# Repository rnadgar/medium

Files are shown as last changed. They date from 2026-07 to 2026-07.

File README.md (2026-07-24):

# OpenRegister — Zigbee Smart HVAC Register

A battery-powered, drop-in smart floor register for **room-by-room temperature
control** with Home Assistant. Replaces a standard 4"×10" floor register with a
3D-printed unit containing a stepper-driven damper, limit switches, a
differential-pressure fail-safe, and a Zigbee radio that runs 1–2+ years on
4× AA lithium cells.

```
Wall temp sensor ──► Home Assistant ──► Zigbee ──► register damper position
                          ▲                              │
                          └──── pressure / battery ◄─────┘
```

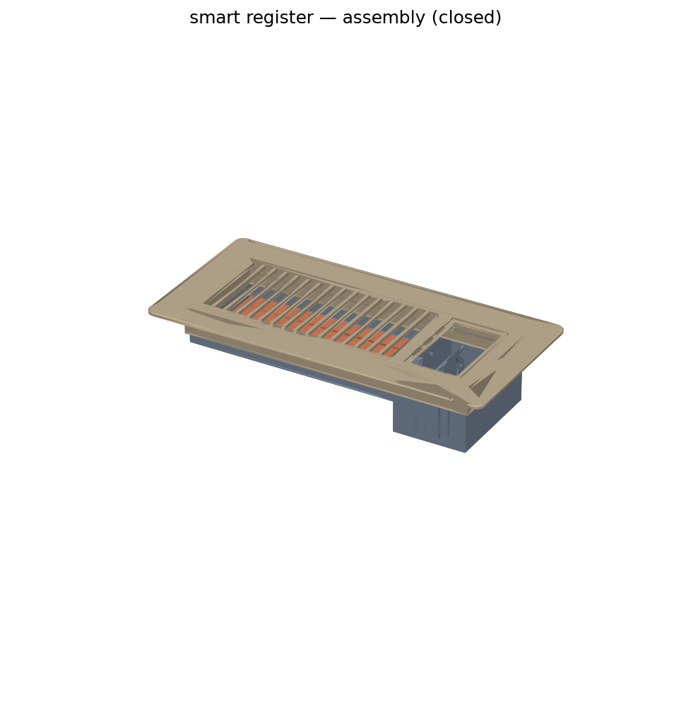
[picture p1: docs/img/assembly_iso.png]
assembly


| PCB rev A (front) | Mechanism (faceplate hidden) |
|---|---|
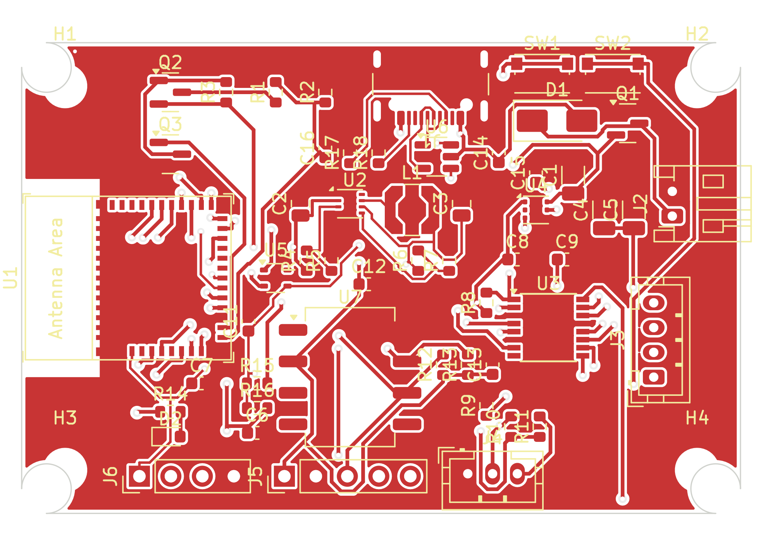
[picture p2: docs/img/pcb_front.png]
pcb
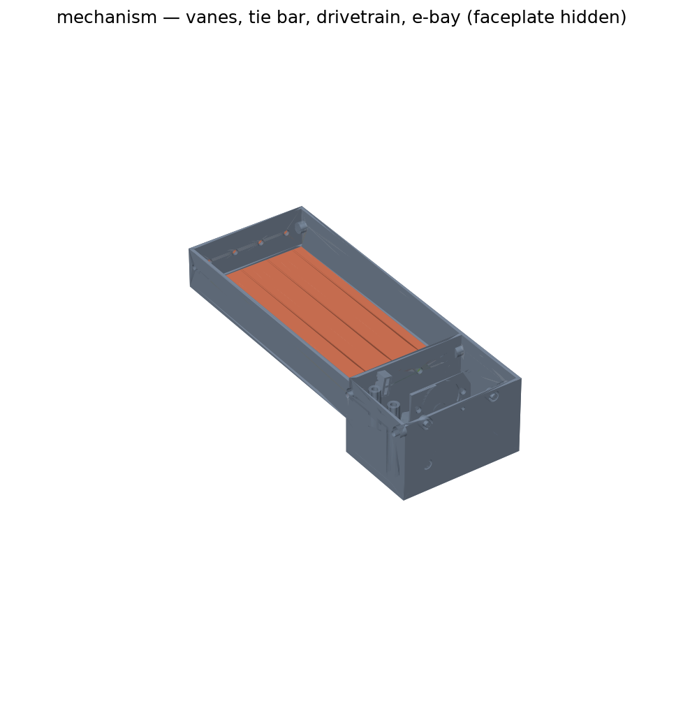
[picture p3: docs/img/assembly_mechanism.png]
mechanism
|  |  |

## Highlights

- **Zigbee sleepy end device** (ESP32-C6) — pairs with Zigbee2MQTT or ZHA and
  appears in Home Assistant as a `cover` entity with a position slider.
- **Fine-grained damper control** — 28BYJ-48 geared stepper (bipolar-modified,
  DRV8833 driver) with limit switches for homing; motor fully de-energized
  between moves.
- **Autonomous pressure fail-safe** — an onboard differential pressure sensor
  trips the damper fully open if duct static pressure exceeds a threshold,
  with **no network dependency**; an HA-side blueprint additionally keeps the
  total open area across all registers above a configurable floor.
- **Ultra-low power** — ~150 µA average draw ⇒ ≈2.4 years on 4× AA lithium
  (see [docs/power-budget.md](docs/power-budget.md)).
- **Fully parametric CAD** — the whole register is generated from one
  parameters dataclass ([build123d](https://build123d.readthedocs.io/)), so
  other register sizes are a preset away.

## Repository layout

| Path | Contents |
|---|---|
| [`docs/`](docs/) | Architecture, power budget, BOM, assembly, pairing guides |
| [`firmware/`](firmware/) | ESP-IDF + esp-zigbee-sdk firmware (C) with host-runnable unit tests |
| [`hardware/pcb/`](hardware/pcb/) | KiCad schematic + layout, fab outputs |
| [`cad/`](cad/) | build123d parametric models, STL/STEP export, pytest checks |
| [`homeassistant/`](homeassistant/) | Zigbee2MQTT converter, ZHA quirk, HA blueprints |

## Getting started

1. **Read** [docs/architecture.md](docs/architecture.md) for the system design.
2. **Buy** the parts in [docs/bom.md](docs/bom.md).
3. **Print** the register: `cd cad && pip install -e . && python export.py`
   then print the STLs in `cad/out/stl/` ([docs/assembly.md](docs/assembly.md)).
4. **Flash** the firmware: `cd firmware && idf.py set-target esp32c6 && idf.py flash`.
5. **Pair** with Zigbee2MQTT and import the blueprints
   ([docs/pairing-setup.md](docs/pairing-setup.md)).

## Status

Rev A — design complete, hardware validation in progress. Firmware bring-up
happens on an ESP32-C6-DevKitC-1 with breakout boards **before** ordering the
custom PCB; see the dev-bench section of the BOM.

## License

MIT — see [LICENSE](LICENSE).

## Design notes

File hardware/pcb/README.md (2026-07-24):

# smart-register rev A — PCB

58 × 38 mm 2-layer board for the e-bay of the smart register. ESP32-C6-MINI-1
(Zigbee), TPS62125 always-on 3.3 V buck, DRV8833 stepper driver on a
TPS22810-switched battery rail, SiP32431-switched 3.3 V sensor rail,
XGZP6897D on-board differential pressure sensor (or SDP810 on the J5 remote
header), gated battery divider, limit-switch inputs, USB-C flash/debug.

## Layout facts

- Outline/mounting contract with `cad/smart_register/params.py`:
  58 × 38 mm, M3 holes inset 3.5 mm from each corner.
- ESP32-C6 antenna at the **left board edge** with a copper/track keep-out
  under it; the CAD e-bay mounts the board vertically so this edge sits in
  the top 15 mm of the register (above the steel boot line).
- Net classes: `Default` 0.3 mm / 0.2 mm clearance; `USB` (fine-pitch USB-C
  and WSON buck nets) 0.2 mm / 0.13 mm.
- DRC: clean under KiCad 8 with the project file's net classes and severity
  settings (silk cosmetics and lib checks off — all footprints are embedded).

## Regenerating everything

The whole board is **generated from code** — do not hand-edit the outputs;
edit `tools/design.py` (netlist), `tools/gen_pcb.py` (placement), or the
generators, then:

```bash
cd hardware/pcb/tools
python3 design.py            # validate the canonical netlist
python3 gen_project.py       # .kicad_pro + lib tables
python3 gen_schematic.py     # smart-register.kicad_sch
python3 check_netlist.py     # schematic netlist == design.py (kicad-cli)
python3 gen_pcb.py           # placed board + Specctra DSN
java -jar freerouting.jar -de ../smart-register/smart-register.dsn \
     -do ../smart-register/smart-register.ses -mp 30
python3 import_ses.py        # tracks/vias + repairs + pours + stitching + DRC
python3 gen_fab.py           # gerbers/drill/BOM/CPL into ../fab/
```

Requires KiCad 7+ (pcbnew python + kicad-cli) and Java 17+ for
[Freerouting](https://github.com/freerouting/freerouting). The committed
`smart-register.ses` reproduces the committed routing exactly; only re-run
Freerouting if you change the design, and re-check DRC afterwards
(`import_ses.py` prints "DRC real issues: none" on success — its hand-repair
coordinates in `REPAIRS` are tied to the committed session and must be
revisited after any re-route).

## Ordering (JLCPCB)

1. Upload `fab/smart-register-gerbers.zip` — 2-layer, 1.6 mm FR4, any color,
   HASL or ENIG, no special options.
2. Optional assembly: `fab/bom.csv` + `fab/cpl.csv` (verify rotations in
   their preview — generated rotations follow KiCad, JLC sometimes differs
   per package).
3. **Order after validating firmware on the dev bench** (see
   `docs/bom.md` section E) — the board is validation, not the critical path.

## Bring-up checklist

1. Visual + shorts check (VBAT–GND, 3V3–GND).
2. Batteries in (or USB — SS14 feeds the pack rail at ~4.7 V for bench work):
   3.3 V rail present, ~40 µA sleep draw after flashing.
3. Flash via USB-C (`idf.py -p /dev/ttyACM0 flash` — USB-Serial-JTAG).
4. `MOTOR_PWR_EN` high → VMOT = pack voltage, sensor rail 3.3 V.
5. Motor moves, limit switches read, pressure sample returns plausible Pa.
6. Join Zigbee, then the `docs/pairing-setup.md` flow.

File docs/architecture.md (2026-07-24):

# System Architecture

Battery-powered Zigbee smart register: a drop-in 4"×10" floor register with a
stepper-actuated multi-vane damper, limit switches, differential-pressure
fail-safe, and a ~2-year battery life on 4× AA lithium (LiFeS2) cells.

## Block diagram

```mermaid
flowchart LR
    subgraph pack["4x AA LiFeS2 pack (6.0-7.2 V)"]
        BATT[VBAT]
    end
    BATT --> RPP["Reverse-polarity P-FET"]
    RPP --> BUCK["TPS62125 buck\n3.3 V always-on, Iq ~13 uA"]
    RPP --> LSW["TPS22810 load switch\nMOTOR_PWR_EN"]
    BUCK --> C6["ESP32-C6-MINI-1\nZigbee sleepy end device"]
    BUCK --> SSW["SiP32431 load switch\n3V3_SENS, MOTOR_PWR_EN"]
    LSW --> DRV["DRV8833\nstepper driver"]
    SSW --> SDP["Pressure sensor\nXGZP6897D onboard / SDP810 header (I2C)"]
    DRV --> MOT["28BYJ-48 stepper\n(bipolar mod) + gear train"]
    MOT --> VANES["Linked damper vanes"]
    SW1["Limit switch OPEN"] --> C6
    SW2["Limit switch CLOSED"] --> C6
    SDP -->|I2C| C6
    C6 -->|AIN1..BIN2| DRV
    RPP --> DIV["Gated divider\nVBAT_SENSE"]
    DIV --> C6
```

Two power domains:

- **Always-on 3.3 V** (TPS62125): the ESP32-C6 and nothing else. The buck's
  ~13 µA quiescent current plus the C6 in light sleep sets the sleep floor.
- **Switched VBAT "VMOT"** (TPS22810, `MOTOR_PWR_EN`): DRV8833 stepper
  driver. (TPS22919/SiP32431-class switches are 5.5 V-max parts — below the
  7.2 V fresh pack — hence the 18 V-rated TPS22810 here.)
- **Switched 3.3 V "3V3_SENS"** (SiP32431 from the 3.3 V rail, same
  `MOTOR_PWR_EN` signal): pressure sensor + I2C pull-ups. Energized only
  during moves and pressure samples; parked leakage ≤ 1 µA total.

The pressure sensor has two mutually exclusive fit options: XGZP6897D
directly on board (cost-down default) or an SDP810 connected to the 5-pin
remote-sensor header (premium accuracy; also mechanically flexible for tube
routing).

## Pin map

Single source of truth — `firmware/main/board.h` mirrors this table and is
selected per-board with `idf.py menuconfig` (Kconfig choice `BOARD_*`).

| Signal | Rev A GPIO | DevKitC-1 GPIO | Dir | Notes |
|---|---|---|---|---|
| `VBAT_SENSE` | 0 | 0 | AI | ADC1_CH0, 1 M / 330 k divider |
| `VBAT_SENSE_EN` | 1 | 1 | O | High = divider connected (NFET → P-FET) |
| `MOTOR_AIN1` | 2 | 2 | O | DRV8833 AIN1 |
| `MOTOR_AIN2` | 3 | 3 | O | DRV8833 AIN2 |
| `MOTOR_BIN1` | 4 | 4 | O | DRV8833 BIN1 |
| `MOTOR_BIN2` | 5 | 5 | O | DRV8833 BIN2 |
| `I2C_SDA` | 6 | 6 | IO | Pressure sensor bus (on switched rail) |
| `I2C_SCL` | 7 | 7 | O | |
| `BOOT_BTN` | 9 | 9 | I | Boot strap; long-press = factory reset / pair |
| `USB_D-` / `USB_D+` | 12 / 13 | (USB conn) | IO | USB-Serial-JTAG flash/debug |
| `UART_TX` / `UART_RX` | 16 / 17 | 16 / 17 | O/I | Debug header |
| `LIMIT_OPEN` | 18 | 18 | I | Closes to GND at full-open travel |
| `LIMIT_CLOSED` | 19 | 19 | I | Closes to GND at full-closed travel |
| `STATUS_LED` | 20 | 8 (onboard) | O | Identify blink, fault codes |
| `MOTOR_PWR_EN` | 21 | 21 | O | Load-switch EN, high = motor + sensor rails powered |
| `LIMIT_SENSE_EN` | 22 | 22 | O | Sources the limit-switch pull-ups during moves only |
| `SENS_IRQ` (spare) | 23 | 23 | I | Reserved on the remote-sensor header |

> GPIO10/11 are **not bonded out** on the ESP32-C6-MINI-1 module — do not
> assign them. Free for future use: GPIO14, GPIO15.

Limit switches are wired switch→GND on the input side with their pull-up side
fed from `LIMIT_SENSE_EN`, so there is **zero standby current** through the
switch network; inputs are only meaningful while the CPU is awake and moving
the motor (no GPIO wake needed).

## Zigbee device model

Sleepy End Device (`rx_on_when_idle = false`), one application endpoint.

Manufacturer **"OpenRegister"**, model **"SR-4x10"**, endpoint **1**, profile
Home Automation (0x0104), device id Window Covering Device (0x0202).

| Cluster | ID | Role | Use |
|---|---|---|---|
| Basic | 0x0000 | server | mfr/model/date/sw build strings |
| Power Configuration | 0x0001 | server | `BatteryVoltage` 0x0020, `BatteryPercentageRemaining` 0x0021 (reportable, 0.5 % units) |
| Identify | 0x0003 | server | status LED blink |
| Poll Control | 0x0020 | server | coordinator-tunable long/short poll |
| Window Covering | 0x0102 | server | primary control — see below |
| Pressure Measurement | 0x0403 | server | `ScaledValue` 0x0010 / `Scale` 0x0014 (Pa resolution); `MeasuredValue` also kept coherent |
| OTA Upgrade | 0x0019 | client | phase 2 (partition slots reserved now) |
| **Fail-safe (mfr-specific)** | **0xFC00** | server | see table below |

### Window Covering semantics — the one inversion, stated once

ZCL lift percentage: **0 % = fully open (damper open, max airflow), 100 % =
fully closed**. Firmware stores damper position as `open_pct` and maps at the
cluster boundary only:

```
lift_pct = 100 - open_pct
```

`CurrentPositionLiftPercentage` (0x0008) is reportable. Supported commands:
`UpOrOpen` (0x00), `DownOrClose` (0x01), `Stop` (0x02),
`GoToLiftPercentage` (0x05). Zigbee2MQTT/ZHA map this to an HA `cover`
entity whose position slider reads 100 = open — consistent with "open =
airflow" everywhere the user sees it.

### Fail-safe cluster 0xFC00 (manufacturer code 0x131B)

| Attr | ID | Type | Access | Default | Meaning |
|---|---|---|---|---|---|
| `failsafe_tripped` | 0x0000 | bool | R, reportable | false | Local fail-open is active |
| `failsafe_threshold_pa` | 0x0001 | uint16 | RW, NVS | 150 | Trip when pressure > this for 2 samples |
| `failsafe_clear_hysteresis_pa` | 0x0002 | uint16 | RW, NVS | 30 | Clear below (threshold − hysteresis) |
| `last_trip_pressure_pa` | 0x0003 | uint16 | R | 0 | Pressure at last trip |
| `auto_clear_enable` | 0x0004 | bool | RW, NVS | true | Resume commanded position when pressure recovers; false = latch until cleared from HA |
| `fault_code` | 0x0005 | enum8 | R, reportable | 0 | 0 = none, 1 = homing timeout, 2 = stall, 3 = sensor fail |

Rationale for a custom cluster over IAS Zone: IAS enrollment is stateful and
fragile on a sleepy device, and trip latency to HA is irrelevant — the local
state machine has already opened the damper before HA hears about it. The
custom cluster also keeps trip status and its configuration attributes
together, and the Zigbee2MQTT external converter is needed regardless.

## Sleep & polling strategy

- **Automatic light sleep** (`CONFIG_PM_ENABLE` + tickless idle +
  `esp_zb_sleep_enable(true)`). The Zigbee stack schedules MAC data polls;
  the chip light-sleeps between them (~35–50 µA including regulator).
  Deep sleep is deliberately not used: it drops stack state, forcing an
  expensive re-init/rejoin each wake and ruining command latency.
- **Long poll ≈ 5 s** — parent routers buffer indirect transmissions ~7.68 s,
  so 5 s guarantees no lost commands and bounds command latency at ~5 s.
  **Short poll (fast polling)** engages during joins, OTA, and for a few
  seconds after any command or report.
- **Pressure sampling** on an `esp_timer`: 30 s base period, adaptive —
  120 s when the blower has been off for a while (pressure ≈ 0), 15 s while
  pressure indicates the blower is running or near threshold.
- **Reporting**: position on move complete; pressure on ≥ 10 Pa delta;
  battery daily; `failsafe_tripped` and `fault_code` immediately (with a
  fast-poll window so the report flushes through the parent promptly).

## Damper control

- 28BYJ-48 (bipolar-modified) half-stepped at 500–800 half-steps/s,
  ~4096 half-steps/output-rev, further reduced ~3:1 by a printed pinion +
  sector gear on the master vane shaft. The reduction adds torque margin and
  makes the linkage effectively non-backdrivable so the damper holds position
  with the coils dead.
- **Move sequence**: `MOTOR_PWR_EN` high → 5 ms rail settle →
  `LIMIT_SENSE_EN` high → step → coils off → both enables low.
- **Homing** (first boot, position-invalid flag, or brown-out): seek the
  CLOSED switch at reduced speed, debounce (2 consecutive reads), zero the
  counter, back off. Full range calibrated once against the OPEN switch;
  `range_steps` persisted in NVS.
- **Position persistence**: a `move_pending` dirty flag is written to NVS
  before each move and cleared (with the new position) after completion —
  an unexpected reset mid-move forces re-homing instead of trusting a stale
  count.
- **Stall/timeout**: watchdog at expected steps × 1.25; on failure set
  `fault_code`, report, and refuse further moves except fail-open attempts.

## Fail-safe state machine (`failsafe.c`, host-testable)

```
IDLE ──blower pressure rises──► ARMED ──p > threshold ×2 samples──► TRIPPED
 ▲                                │                                   │
 └──────p ≈ 0 sustained───────────┘             p < threshold − hyst ×M samples
                                                                      ▼
                                              RECOVERING ──auto_clear?──► IDLE
                                              (else latch in TRIPPED until HA clears)
```

On TRIPPED the module calls straight into the damper API (no Zigbee
involvement) to drive 100 % open, then reports. The module has **zero
ESP-IDF includes** — inputs are `(pressure_pa, now_ms)`, outputs are a
requested position + report flags — so it compiles and runs on the host
(`firmware/test/host/`).

## Pressure sensing

Sensirion SDP810-500Pa differential sensor: duct-side port on a printed
snorkel below the frame (facing away from direct flow — static pressure, not
dynamic), room-side reference port venting into the electronics bay.
2–3 mm silicone tube to the sensor barbs. The sensor sits on the switched
rail and is powered only for the ~50 ms sampling window. Cost-down path:
XGZP6897D (±500 Pa, I2C) footprint is on the board; it needs a firmware
auto-zero (long-term average while blower off) to compensate zero drift.

## Battery measurement

LiFeS2 has a flat open-circuit voltage curve, so unloaded voltage is nearly
useless for state of charge. `battery.c` therefore samples the gated divider
**under motor load** (during a move) plus a daily unloaded reading:
loaded-voltage sag is the honest state-of-charge signal. Reported via Power
Configuration in 100 mV / 0.5 % units.

## Failure modes & mitigations

| Failure | Behavior |
|---|---|
| Network down / coordinator dead | Local fail-safe still trips and opens the damper (zero network dependency) |
| Battery dead | No fail-open — mitigated by early low-battery reporting and the HA pressure-floor blueprint treating unavailable registers as **closed** |
| Homing/stall fault | `fault_code` set + reported; only fail-open moves attempted afterwards |
| Sensor fault (I2C errors) | `fault_code = 3`; damper is driven fully open as a precaution |
| Reset mid-move | `move_pending` flag forces re-home before the next move |

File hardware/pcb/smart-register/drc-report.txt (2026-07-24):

** Drc report for /home/user/medium/hardware/pcb/smart-register/smart-register.kicad_pcb **
** Created on 2026-07-24 16:54:14 **

** Found 135 DRC violations **
[silk_overlap]: Silkscreen overlap
    Rule: board setup constraints silk; Severity: warning
    @(149.9500 mm, 113.0000 mm): Reference 'J2'
    @(150.3100 mm, 114.2113 mm): Line on F.Silkscreen
[silk_overlap]: Silkscreen overlap
    Rule: board setup constraints silk; Severity: warning
    @(147.5500 mm, 113.5000 mm): Reference 'C5'
    @(147.9100 mm, 114.2113 mm): Line on F.Silkscreen
[silk_overlap]: Silkscreen overlap
    Rule: board setup constraints silk; Severity: warning
    @(142.6500 mm, 110.7000 mm): Reference 'C1'
    @(141.5000 mm, 111.5500 mm): Reference 'U4'
[silk_overlap]: Silkscreen overlap
    Rule: board setup constraints silk; Severity: warning
    @(145.5000 mm, 104.0500 mm): Line on F.Silkscreen
    @(148.9000 mm, 104.1000 mm): Reference 'Q1'
[silk_overlap]: Silkscreen overlap
    Rule: board setup constraints silk; Severity: warning
    @(143.2000 mm, 103.8000 mm): Reference 'D1'
    @(139.8000 mm, 104.0500 mm): Line on F.Silkscreen
[silk_overlap]: Silkscreen overlap
    Rule: board setup constraints silk; Severity: warning
    @(134.5225 mm, 126.2373 mm): Line on F.Silkscreen
    @(134.5700 mm, 126.0000 mm): Reference 'R13'
[silk_overlap]: Silkscreen overlap
    Rule: board setup constraints silk; Severity: warning
    @(136.5225 mm, 126.2373 mm): Line on F.Silkscreen
    @(136.5700 mm, 126.0000 mm): Reference 'C13'
[silk_overlap]: Silkscreen overlap
    Rule: board setup constraints silk; Severity: warning
    @(140.0225 mm, 131.2373 mm): Line on F.Silkscreen
    @(140.3700 mm, 131.0000 mm): Reference 'R11'
[silk_overlap]: Silkscreen overlap
    Rule: board setup constraints silk; Severity: warning
    @(138.0700 mm, 131.0000 mm): Reference 'R10'
    @(138.0000 mm, 131.9000 mm): Reference 'J4'
[silk_overlap]: Silkscreen overlap
    Rule: board setup constraints silk; Severity: warning
    @(133.0700 mm, 117.6000 mm): Reference 'R7'
    @(132.5225 mm, 117.8373 mm): Line on F.Silkscreen
[silk_overlap]: Silkscreen overlap
    Rule: board setup constraints silk; Severity: warning
    @(133.0000 mm, 107.9000 mm): Reference 'J1'
    @(133.5000 mm, 107.6400 mm): Line on F.Silkscreen
[silk_overlap]: Silkscreen overlap
    Rule: board setup constraints silk; Severity: warning
    @(133.0000 mm, 107.9000 mm): Reference 'J1'
    @(133.5000 mm, 107.6400 mm): Line on F.Silkscreen
[silk_overlap]: Silkscreen overlap
    Rule: board setup constraints silk; Severity: warning
    @(133.0000 mm, 107.9000 mm): Reference 'J1'
    @(-1.3000 mm, -1.5100 mm): Polygon on F.Silkscreen
[silk_overlap]: Silkscreen overlap
    Rule: board setup constraints silk; Severity: warning
    @(116.8700 mm, 122.5000 mm): Reference 'C11'
    @(116.9000 mm, 112.4000 mm): Line on F.Silkscreen
[silk_overlap]: Silkscreen overlap
    Rule: board setup constraints silk; Severity: warning
    @(123.5225 mm, 117.8373 mm): Line on F.Silkscreen
    @(123.5700 mm, 117.6000 mm): Reference 'R5'
[silk_overlap]: Silkscreen overlap
    Rule: board setup constraints silk; Severity: warning
    @(127.0225 mm, 109.1373 mm): Line on F.Silkscreen
    @(127.3700 mm, 108.9000 mm): Reference 'R18'
[silk_overlap]: Silkscreen overlap
    Rule: board setup constraints silk; Severity: warning
    @(119.0000 mm, 130.0700 mm): Reference 'C6'
    @(118.7627 mm, 130.0225 mm): Line on F.Silkscreen
[silk_overlap]: Silkscreen overlap
    Rule: board setup constraints silk; Severity: warning
    @(112.0000 mm, 130.3700 mm): Reference 'D2'
    @(111.7627 mm, 130.3225 mm): Line on F.Silkscreen
[silk_overlap]: Silkscreen overlap
    Rule: board setup constraints silk; Severity: warning
    @(118.8700 mm, 135.0000 mm): Reference 'J5'
    @(118.4500 mm, 136.3300 mm): Line on F.Silkscreen
[silk_overlap]: Silkscreen overlap
    Rule: board setup constraints silk; Severity: warning
    @(118.7627 mm, 128.0225 mm): Line on F.Silkscreen
    @(119.0000 mm, 128.0700 mm): Reference 'R16'
[silk_overlap]: Silkscreen overlap
    Rule: board setup constraints silk; Severity: warning
    @(121.5700 mm, 117.6000 mm): Reference 'R4'
    @(119.7900 mm, 117.8400 mm): Line on F.Silkscreen
[silk_overlap]: Silkscreen overlap
    Rule: board setup constraints silk; Severity: warning
    @(121.5700 mm, 117.6000 mm): Reference 'R4'
    @(120.5000 mm, 116.7500 mm): Reference 'U5'
[silk_overlap]: Silkscreen overlap
    Rule: board setup constraints silk; Severity: warning
    @(116.9000 mm, 125.6000 mm): Line on F.Silkscreen
    @(114.5000 mm, 126.0700 mm): Reference 'C7'
[silk_over_copper]: Silkscreen clipped by solder mask
    Local override; Severity: warning
    @(121.5700 mm, 117.6000 mm): Reference 'R4'
[silk_over_copper]: Silkscreen clipped by solder mask
    Local override; Severity: warning
    @(131.5000 mm, 110.5000 mm): Reference 'L1'
[silk_over_copper]: Silkscreen clipped by solder mask
    Local override; Severity: warning
    @(119.0000 mm, 130.0700 mm): Reference 'C6'
[silk_over_copper]: Silkscreen clipped by solder mask
    Local override; Severity: warning
    @(112.0000 mm, 130.3700 mm): Reference 'D2'
[silk_over_copper]: Silkscreen clipped by solder mask
    Local override; Severity: warning
    @(149.9500 mm, 113.0000 mm): Reference 'J2'
[silk_over_copper]: Silkscreen clipped by solder mask
    Local override; Severity: warning
    @(132.5700 mm, 126.0000 mm): Reference 'R12'
[silk_over_copper]: Silkscreen clipped by solder mask
    Local override; Severity: warning
    @(145.1500 mm, 113.5000 mm): Reference 'C4'
[silk_over_copper]: Silkscreen clipped by solder mask
    Local override; Severity: warning
    @(116.8700 mm, 122.5000 mm): Reference 'C11'
[silk_over_copper]: Silkscreen clipped by solder mask
    Local override; Severity: warning
    @(134.5700 mm, 126.0000 mm): Reference 'R13'
[silk_over_copper]: Silkscreen clipped by solder mask
    Local override; Severity: warning
    @(148.9000 mm, 104.1000 mm): Reference 'Q1'
[silk_over_copper]: Silkscreen clipped by solder mask
    Local override; Severity: warning
    @(138.0700 mm, 131.0000 mm): Reference 'R10'
[silk_over_copper]: Silkscreen clipped by solder mask
    Local override; Severity: warning
    @(126.5000 mm, 120.5500 mm): Reference 'U7'
[silk_over_copper]: Silkscreen clipped by solder mask
    Local override; Severity: warning
    @(119.0000 mm, 128.0700 mm): Reference 'R16'
[silk_over_copper]: Silkscreen clipped by solder mask
    Local override; Severity: warning
    @(133.0000 mm, 107.9000 mm): Reference 'J1'
[silk_over_copper]: Silkscreen clipped by solder mask
    Local override; Severity: warning
    @(125.0700 mm, 108.9000 mm): Reference 'R17'
[silk_over_copper]: Silkscreen clipped by solder mask
    Local override; Severity: warning
    @(133.5000 mm, 106.8000 mm): Reference 'U6'
[silk_over_copper]: Silkscreen clipped by solder mask
    Local override; Severity: warning
    @(123.5700 mm, 117.6000 mm): Reference 'R5'
[silk_over_copper]: Silkscreen clipped by solder mask
    Local override; Severity: warning
    @(133.0700 mm, 117.6000 mm): Reference 'R7'
[silk_over_copper]: Silkscreen clipped by solder mask
    Local override; Severity: warning
    @(133.8200 mm, 113.0000 mm): Reference 'C3'
[silk_over_copper]: Silkscreen clipped by solder mask
    Local override; Severity: warning
    @(143.2000 mm, 103.8000 mm): Reference 'D1'
[silk_over_copper]: Silkscreen clipped by solder mask
    Local override; Severity: warning
    @(127.3700 mm, 108.9000 mm): Reference 'R18'
[silk_over_copper]: Silkscreen clipped by solder mask
    Local override; Severity: warning
    @(141.5000 mm, 111.5500 mm): Reference 'U4'
[silk_over_copper]: Silkscreen clipped by solder mask
    Local override; Severity: warning
    @(140.3700 mm, 131.0000 mm): Reference 'R11'
[silk_over_copper]: Silkscreen clipped by solder mask
    Local override; Severity: warning
    @(136.5700 mm, 126.0000 mm): Reference 'C13'
[lib_footprint_issues]: The current configuration does not include the library ''.
    Local override; Severity: warning
    @(120.5000 mm, 104.0000 mm): Footprint R1
[lib_footprint_issues]: The current configuration does not include the library ''.
    Local override; Severity: warning
    @(123.0000 mm, 117.6000 mm): Footprint R4
[lib_footprint_issues]: The current configuration does not include the library ''.
    Local override; Severity: warning
    @(119.0000 mm, 127.5000 mm): Footprint R15
[lib_footprint_issues]: The current configuration does not include the library ''.
    Local override; Severity: warning
    @(131.5000 mm, 113.5000 mm): Footprint L1
[lib_footprint_issues]: The current configuration does not include the library ''.
    Local override; Severity: warning
    @(119.0000 mm, 131.5000 mm): Footprint C6
[lib_footprint_issues]: The current configuration does not include the library ''.
    Local override; Severity: warning
    @(120.5000 mm, 119.0000 mm): Footprint U5
[lib_footprint_issues]: The current configuration does not include the library ''.
    Local override; Severity: warning
    @(112.0000 mm, 131.8000 mm): Footprint D2
[lib_footprint_issues]: The current configuration does not include the library ''.
    Local override; Severity: warning
    @(116.5000 mm, 104.0000 mm): Footprint R3
[lib_footprint_issues]: The current configuration does not include the library ''.
    Local override; Severity: warning
    @(126.5000 mm, 113.0000 mm): Footprint U2
[lib_footprint_issues]: The current configuration does not include the library ''.
    Local override; Severity: warning
    @(152.5000 mm, 114.0000 mm): Footprint J2
[lib_footprint_issues]: The current configuration does not include the library ''.
    Local override; Severity: warning
    @(124.5000 mm, 104.0000 mm): Footprint R2
[lib_footprint_issues]: The current configuration does not include the library ''.
    Local override; Severity: warning
    @(149.4000 mm, 113.5000 mm): Footprint C5
[lib_footprint_issues]: The current configuration does not include the library ''.
    Local override; Severity: warning
    @(151.0000 mm, 127.0000 mm): Footprint J3
[lib_footprint_issues]: The current configuration does not include the library ''.
    Local override; Severity: warning
    @(112.0000 mm, 104.0000 mm): Footprint Q2
[lib_footprint_issues]: The current configuration does not include the library ''.
    Local override; Severity: warning
    @(137.5000 mm, 121.0000 mm): Footprint R8
[lib_footprint_issues]: The current configuration does not include the library ''.
    Local override; Severity: warning
    @(144.0000 mm, 117.5000 mm): Footprint C9
[lib_footprint_issues]: The current configuration does not include the library ''.
    Local override; Severity: warning
    @(121.2000 mm, 135.0000 mm): Footprint J5
[lib_footprint_issues]: The current configuration does not include the library ''.
    Local override; Severity: warning
    @(138.5000 mm, 108.9000 mm): Footprint C14
[lib_footprint_issues]: The current configuration does not include the library ''.
    Local override; Severity: warning
    @(134.0000 mm, 126.0000 mm): Footprint R12
[lib_footprint_issues]: The current configuration does not include the library ''.
    Local override; Severity: warning
    @(109.5000 mm, 135.0000 mm): Footprint J6
[lib_footprint_issues]: The current configuration does not include the library ''.
    Local override; Severity: warning
    @(147.0000 mm, 113.5000 mm): Footprint C4
[lib_footprint_issues]: The current configuration does not include the library ''.
    Local override; Severity: warning
    @(144.5000 mm, 110.7000 mm): Footprint C1
[lib_footprint_issues]: The current configuration does not include the library ''.
    Local override; Severity: warning
    @(112.0000 mm, 109.0000 mm): Footprint Q3
[lib_footprint_issues]: The current configuration does not include the library ''.
    Local override; Severity: warning
    @(147.7000 mm, 102.5000 mm): Footprint SW2
[lib_footprint_issues]: The current configuration does not include the library ''.
    Local override; Severity: warning
    @(118.3000 mm, 122.5000 mm): Footprint C11
[lib_footprint_issues]: The current configuration does not include the library ''.
    Local override; Severity: warning
    @(132.0000 mm, 117.6000 mm): Footprint R6
[lib_footprint_issues]: The current configuration does not include the library ''.
    Local override; Severity: warning
    @(136.0000 mm, 126.0000 mm): Footprint R13
[lib_footprint_issues]: The current configuration does not include the library ''.
    Local override; Severity: warning
    @(148.9000 mm, 106.5000 mm): Footprint Q1
[lib_footprint_issues]: The current configuration does not include the library ''.
    Local override; Severity: warning
    @(137.5000 mm, 129.3000 mm): Footprint R9
[lib_footprint_issues]: The current configuration does not include the library ''.
    Local override; Severity: warning
    @(139.5000 mm, 131.0000 mm): Footprint R10
[lib_footprint_issues]: The current configuration does not include the library ''.
    Local override; Severity: warning
    @(114.5000 mm, 127.5000 mm): Footprint C7
[lib_footprint_issues]: The current configuration does not include the library ''.
    Local override; Severity: warning
    @(126.5000 mm, 127.0000 mm): Footprint U7
[lib_footprint_issues]: The current configuration does not include the library ''.
    Local override; Severity: warning
    @(128.0000 mm, 119.5000 mm): Footprint C12
[lib_footprint_issues]: The current configuration does not include the library ''.
    Local override; Severity: warning
    @(103.5000 mm, 103.5000 mm): Footprint H1
[lib_footprint_issues]: The current configuration does not include the library ''.
    Local override; Severity: warning
    @(154.5000 mm, 134.5000 mm): Footprint H4
[lib_footprint_issues]: The current configuration does not include the library ''.
    Local override; Severity: warning
    @(119.0000 mm, 129.5000 mm): Footprint R16
[lib_footprint_issues]: The current configuration does not include the library ''.
    Local override; Severity: warning
    @(141.5000 mm, 110.5000 mm): Footprint C15
[lib_footprint_issues]: The current configuration does not include the library ''.
    Local override; Severity: warning
    @(133.0000 mm, 102.4000 mm): Footprint J1
[lib_footprint_issues]: The current configuration does not include the library ''.
    Local override; Severity: warning
    @(126.5000 mm, 108.9000 mm): Footprint R17
[lib_footprint_issues]: The current configuration does not include the library ''.
    Local override; Severity: warning
    @(154.5000 mm, 103.5000 mm): Footprint H2
[lib_footprint_issues]: The current configuration does not include the library ''.
    Local override; Severity: warning
    @(133.5000 mm, 109.2000 mm): Footprint U6
[lib_footprint_issues]: The current configuration does not include the library ''.
    Local override; Severity: warning
    @(103.5000 mm, 134.5000 mm): Footprint H3
[lib_footprint_issues]: The current configuration does not include the library ''.
    Local override; Severity: warning
    @(125.0000 mm, 117.6000 mm): Footprint R5
[lib_footprint_issues]: The current configuration does not include the library ''.
    Local override; Severity: warning
    @(134.5000 mm, 117.6000 mm): Footprint R7
[lib_footprint_issues]: The current configuration does not include the library ''.
    Local override; Severity: warning
    @(124.5000 mm, 108.5000 mm): Footprint C16
[lib_footprint_issues]: The current configuration does not include the library ''.
    Local override; Severity: warning
    @(142.5000 mm, 123.0000 mm): Footprint U3
[lib_footprint_issues]: The current configuration does not include the library ''.
    Local override; Severity: warning
    @(135.5000 mm, 113.0000 mm): Footprint C3
[lib_footprint_issues]: The current configuration does not include the library ''.
    Local override; Severity: warning
    @(112.0000 mm, 129.8000 mm): Footprint R14
[lib_footprint_issues]: The current configuration does not include the library ''.
    Local override; Severity: warning
    @(140.0000 mm, 117.5000 mm): Footprint C8
[lib_footprint_issues]: The current configuration does not include the library ''.
    Local override; Severity: warning
    @(143.2000 mm, 106.3000 mm): Footprint D1
[lib_footprint_issues]: The current configuration does not include the library ''.
    Local override; Severity: warning
    @(128.8000 mm, 108.9000 mm): Footprint R18
[lib_footprint_issues]: The current configuration does not include the library ''.
    Local override; Severity: warning
    @(122.5000 mm, 113.0000 mm): Footprint C2
[lib_footprint_issues]: The current configuration does not include the library ''.
    Local override; Severity: warning
    @(136.0000 mm, 134.8000 mm): Footprint J4
[lib_footprint_issues]: The current configuration does not include the library ''.
    Local override; Severity: warning
    @(141.5000 mm, 113.5000 mm): Footprint U4
[lib_footprint_issues]: The current configuration does not include the library ''.
    Local override; Severity: warning
    @(141.8000 mm, 131.0000 mm): Footprint R11
[lib_footprint_issues]: The current configuration does not include the library ''.
    Local override; Severity: warning
    @(142.0000 mm, 102.5000 mm): Footprint SW1
[lib_footprint_issues]: The current configuration does not include the library ''.
    Local override; Severity: warning
    @(138.0000 mm, 126.0000 mm): Footprint C13
[lib_footprint_issues]: The current configuration does not include the library ''.
    Local override; Severity: warning
    @(108.6000 mm, 119.0000 mm): Footprint U1
[lib_footprint_issues]: The current configuration does not include the library ''.
    Local override; Severity: warning
    @(145.5000 mm, 121.5000 mm): Footprint C10
[silk_edge_clearance]: Silkscreen clipped by board edge
    Rule: board setup constraints silk; Severity: warning
    @(158.0000 mm, 102.0000 mm): Line on Edge.Cuts
    @(151.0400 mm, 116.0600 mm): Line on F.Silkscreen
[silk_edge_clearance]: Silkscreen clipped by board edge
    Rule: board setup constraints silk; Severity: warning
    @(158.0000 mm, 102.0000 mm): Line on Edge.Cuts
    @(156.6000 mm, 114.8000 mm): Line on F.Silkscreen
[silk_edge_clearance]: Silkscreen clipped by board edge
    Rule: board setup constraints silk; Severity: warning
    @(158.0000 mm, 102.0000 mm): Line on Edge.Cuts
    @(156.6000 mm, 114.3000 mm): Line on F.Silkscreen
[silk_edge_clearance]: Silkscreen clipped by board edge
    Rule: board setup constraints silk; Severity: warning
    @(158.0000 mm, 102.0000 mm): Line on Edge.Cuts
    @(158.8600 mm, 113.5000 mm): Line on F.Silkscreen
[silk_edge_clearance]: Silkscreen clipped by board edge
    Rule: board setup constraints silk; Severity: warning
    @(158.0000 mm, 102.0000 mm): Line on Edge.Cuts
    @(154.5000 mm, 112.5000 mm): Line on F.Silkscreen
[silk_edge_clearance]: Silkscreen clipped by board edge
    Rule: board setup constraints silk; Severity: warning
    @(158.0000 mm, 102.0000 mm): Line on Edge.Cuts
    @(158.8600 mm, 109.9400 mm): Line on F.Silkscreen
[silk_edge_clearance]: Silkscreen clipped by board edge
    Rule: board setup constraints silk; Severity: warning
    @(102.0000 mm, 100.0000 mm): Line on Edge.Cuts
    @(147.7000 mm, 100.0500 mm): Reference 'SW2'
[silk_edge_clearance]: Silkscreen clipped by board edge
    Rule: board setup constraints silk; Severity: warning
    @(102.0000 mm, 100.0000 mm): Line on Edge.Cuts
    @(142.0000 mm, 100.0500 mm): Reference 'SW1'
[clearance]: Clearance violation (netclass 'Default' clearance 0.2000 mm; actual 0.1807 mm)
    Rule: netclass 'Default'; Severity: error
    @(131.2500 mm, 107.4792 mm): Track [CC2] on F.Cu, length 1.3992 mm
    @(131.3700 mm, 107.8405 mm): Track [USB_DP_CONN] on F.Cu, length 1.6864 mm
[clearance]: Clearance violation (netclass 'Default' clearance 0.2000 mm; actual 0.1403 mm)
    Rule: netclass 'Default'; Severity: error
    @(129.0042 mm, 109.7250 mm): Track [CC2] on F.Cu, length 3.1760 mm
    @(131.3700 mm, 107.8405 mm): Track [USB_DP_CONN] on F.Cu, length 1.6864 mm
[clearance]: Clearance violation (netclass 'Default' clearance 0.2000 mm; actual 0.1782 mm)
    Rule: netclass 'Default'; Severity: error
    @(132.8668 mm, 104.1223 mm): Track [CC1] on F.Cu, length 1.9561 mm
    @(133.7500 mm, 106.0800 mm): Pad B7 [USB_DN_CONN] of J1 on F.Cu
[clearance]: Clearance violation (netclass 'Default' clearance 0.2000 mm; actual 0.1461 mm)
    Rule: netclass 'Default'; Severity: error
    @(132.9433 mm, 105.2442 mm): Track [USB_DP_CONN] on F.Cu, length 0.4337 mm
    @(132.7500 mm, 106.0800 mm): Pad A7 [USB_DN_CONN] of J1 on F.Cu
[clearance]: Clearance violation (netclass 'Default' clearance 0.2000 mm; actual 0.1608 mm)
    Rule: netclass 'Default'; Severity: error
    @(132.5755 mm, 105.2442 mm): Track [USB_DP_CONN] on F.Cu, length 0.3678 mm
    @(132.7500 mm, 106.0800 mm): Pad A7 [USB_DN_CONN] of J1 on F.Cu
[clearance]: Clearance violation (netclass 'Default' clearance 0.2000 mm; actual 0.1328 mm)
    Rule: netclass 'Default'; Severity: error
    @(132.2500 mm, 105.5697 mm): Track [USB_DP_CONN] on F.Cu, length 0.4603 mm
    @(132.7500 mm, 106.0800 mm): Pad A7 [USB_DN_CONN] of J1 on F.Cu
[clearance]: Clearance violation (netclass 'Default' clearance 0.2000 mm; actual 0.1403 mm)
    Rule: netclass 'Default'; Severity: error
    @(132.2500 mm, 106.9605 mm): Track [USB_DP_CONN] on F.Cu, length 1.2445 mm
    @(129.0042 mm, 109.7250 mm): Track [CC2] on F.Cu, length 3.1760 mm
[clearance]: Clearance violation (netclass 'Default' clearance 0.2000 mm; actual 0.1361 mm)
    Rule: netclass 'Default'; Severity: error
    @(133.7500 mm, 106.5950 mm): Track [USB_DN_CONN] on F.Cu, length 0.5101 mm
    @(133.2500 mm, 106.0800 mm): Pad A6 [USB_DP_CONN] of J1 on F.Cu
[clearance]: Clearance violation (netclass 'Default' clearance 0.2000 mm; actual 0.1757 mm)
    Rule: netclass 'Default'; Severity: error
    @(132.5019 mm, 119.0708 mm): Track [BUCK_FB] on F.Cu, length 1.2685 mm
    @(132.0000 mm, 118.4250 mm): Pad 1 [3V3] of R6 on F.Cu
[clearance]: Clearance violation (netclass 'Default' clearance 0.2000 mm; actual 0.1458 mm)
    Rule: netclass 'Default'; Severity: error
    @(131.5451 mm, 119.0708 mm): Track [BUCK_FB] on F.Cu, length 0.9568 mm
    @(132.0000 mm, 118.4250 mm): Pad 1 [3V3] of R6 on F.Cu
[clearance]: Clearance violation (netclass 'Default' clearance 0.2000 mm; actual 0.1472 mm)
    Rule: netclass 'Default'; Severity: error
    @(130.8825 mm, 118.4082 mm): Track [BUCK_FB] on F.Cu, length 0.9371 mm
    @(131.0111 mm, 117.8763 mm): Via [3V3] on F.Cu - B.Cu
[clearance]: Clearance violation (netclass 'Default' clearance 0.2000 mm; actual 0.1472 mm)
    Rule: netclass 'Default'; Severity: error
    @(130.7303 mm, 118.4082 mm): Track [BUCK_FB] on F.Cu, length 0.1522 mm
    @(131.0111 mm, 117.8763 mm): Via [3V3] on F.Cu - B.Cu
[clearance]: Clearance violation (netclass 'Default' clearance 0.2000 mm; actual 0.1747 mm)
    Rule: netclass 'Default'; Severity: error
    @(130.4186 mm, 118.0965 mm): Track [BUCK_FB] on F.Cu, length 0.4408 mm
    @(131.0111 mm, 117.8763 mm): Via [3V3] on F.Cu - B.Cu
[clearance]: Clearance violation (netclass 'Default' clearance 0.2000 mm; actual 0.1964 mm)
    Rule: netclass 'Default'; Severity: error
    @(130.4186 mm, 117.9443 mm): Track [BUCK_FB] on F.Cu, length 0.1522 mm
    @(131.0111 mm, 117.8763 mm): Via [3V3] on F.Cu - B.Cu
[clearance]: Clearance violation (netclass 'Default' clearance 0.2000 mm; actual 0.1964 mm)
    Rule: netclass 'Default'; Severity: error
    @(127.5324 mm, 115.0581 mm): Track [BUCK_FB] on F.Cu, length 4.0817 mm
    @(131.0111 mm, 117.8763 mm): Via [3V3] on F.Cu - B.Cu
[clearance]: Clearance violation (netclass 'Default' clearance 0.2000 mm; actual 0.1668 mm)
    Rule: netclass 'Default'; Severity: error
    @(131.5538 mm, 116.0861 mm): Track [3V3] on F.Cu, length 0.4562 mm
    @(132.0000 mm, 116.7750 mm): Pad 2 [BUCK_FB] of R6 on F.Cu
[clearance]: Clearance violation (netclass 'Default' clearance 0.2000 mm; actual 0.1889 mm)
    Rule: netclass 'Default'; Severity: error
    @(133.2650 mm, 116.0861 mm): Track [3V3] on F.Cu, length 1.7112 mm
    @(132.0000 mm, 116.7750 mm): Pad 2 [BUCK_FB] of R6 on F.Cu
[clearance]: Clearance violation (netclass 'Default' clearance 0.2000 mm; actual 0.1695 mm)
    Rule: netclass 'Default'; Severity: error
    @(128.2551 mm, 113.8356 mm): Track [3V3] on F.Cu, length 0.8282 mm
    @(127.4500 mm, 113.7500 mm): Pad 5 [BUCK_FB] of U2 on F.Cu
[clearance]: Clearance violation (netclass 'Default' clearance 0.2000 mm; actual 0.1514 mm)
    Rule: netclass 'Default'; Severity: error
    @(130.4581 mm, 116.4087 mm): Track [3V3] on F.Cu, length 3.1155 mm
    @(129.7350 mm, 113.5000 mm): Pad 1 [SW_NODE] of L1 on F.Cu
[clearance]: Clearance violation (netclass 'Default' clearance 0.2000 mm; actual 0.1938 mm)
    Rule: netclass 'Default'; Severity: error
    @(131.2312 mm, 116.4087 mm): Track [3V3] on F.Cu, length 1.2475 mm
    @(132.0000 mm, 116.7750 mm): Pad 2 [BUCK_FB] of R6 on F.Cu
[clearance]: Clearance violation (netclass 'Default' clearance 0.2000 mm; actual 0.1488 mm)
    Rule: netclass 'Default'; Severity: error
    @(124.8847 mm, 119.6500 mm): Track [3V3] on F.Cu, length 1.2608 mm
    @(125.0000 mm, 118.4250 mm): Pad 1 [BUCK_EN] of R5 on F.Cu

** Found 0 unconnected pads **

** Found 0 Footprint errors **

** End of Report **

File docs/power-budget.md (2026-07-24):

# Power Budget

Target: **> 1 year** on 4× AA lithium (LiFeS2, ~3200 mAh usable at low drain),
design estimate **~2.4 years**. All numbers below are design estimates to be
replaced with bench measurements at firmware bring-up (M2) — keep this file
current.

## Assumptions

- Pack: 4× Energizer L91 in series, 6.0 V nominal (7.2 V fresh open-circuit),
  ~3200 mAh to 4.0 V pack cutoff at these drain rates. LiFeS2 chosen for flat
  discharge, low self-discharge (~1 %/yr), and cold-floor performance.
- Always-on rail: TPS62125 (Iq ≈ 13 µA) feeding only the ESP32-C6.
- Switched rail (TPS22919, ≤ 100 nA off-leakage): DRV8833 + SDP810.
- Zigbee sleepy end device, automatic light sleep, long poll 5 s.
- 10 full-range damper moves/day (the room-control blueprint rate-limits and
  quantizes moves precisely to protect this line item).

## Average current

| Item | Basis | Average |
|---|---|---|
| Light-sleep floor | C6 light sleep + buck Iq + leakages ≈ 35–50 µA | **40 µA** |
| Zigbee data polls | ~5 ms @ ~20 mA every 5 s ≈ 0.1 mC/poll | **20 µA** |
| Pressure sampling | SDP810 ~4 mA × 50 ms + wake overhead ≈ 0.5 mC per sample, every 30 s | **17 µA** |
| Reports / rejoins / misc | attribute reports, occasional fast-poll windows | **10 µA** |
| Stepper moves | ~140 mA × 4 s ≈ 0.16 mAh/move × 10/day | **65 µA** |
| **Total** | | **~150 µA** |

## Battery life

```
3200 mAh / 0.15 mA ≈ 21,300 h ≈ 2.4 years
```

Still > 1 year at 2× estimate error. Self-discharge over that period is
negligible for LiFeS2.

## Biggest levers (in order) if measurements disappoint

1. **Long poll interval** 5 s → 7 s (polls scale linearly; latency cost only).
2. **Adaptive pressure sampling** — stretch idle period 120 s → 300 s; the
   fail-safe only needs fast sampling while the blower runs.
3. **Move quantization/rate limiting** in the HA blueprint (already 10 % steps,
   ≥ 5 min between moves).
4. Slower step rate during moves (lower peak current, better torque, slightly
   longer move time — net energy roughly neutral, but reduces battery sag).

## Design rules that protect the budget

- Nothing but the C6 on the always-on rail.
- Motor, driver, and pressure sensor are **hard-switched off** (load switch),
  not software-idled — parked draw is leakage only.
- No continuous pull-ups anywhere: limit-switch bias and the battery divider
  are GPIO-gated and only energized while in use.
- Coils never hold position — the gear train is non-backdrivable instead.

## Measurement plan (M2)

Bench with a µCurrent/joulescope on the pack:

1. Light-sleep floor with radio joined and idle (expect 35–50 µA).
2. Average over 10 min of normal polling (expect ≤ 70 µA incl. floor).
3. Energy per full-range move (expect ≈ 0.16 mAh).
4. Energy per pressure sample (expect ≈ 0.5 mC).
5. 24 h soak average — the number that goes in the table above.

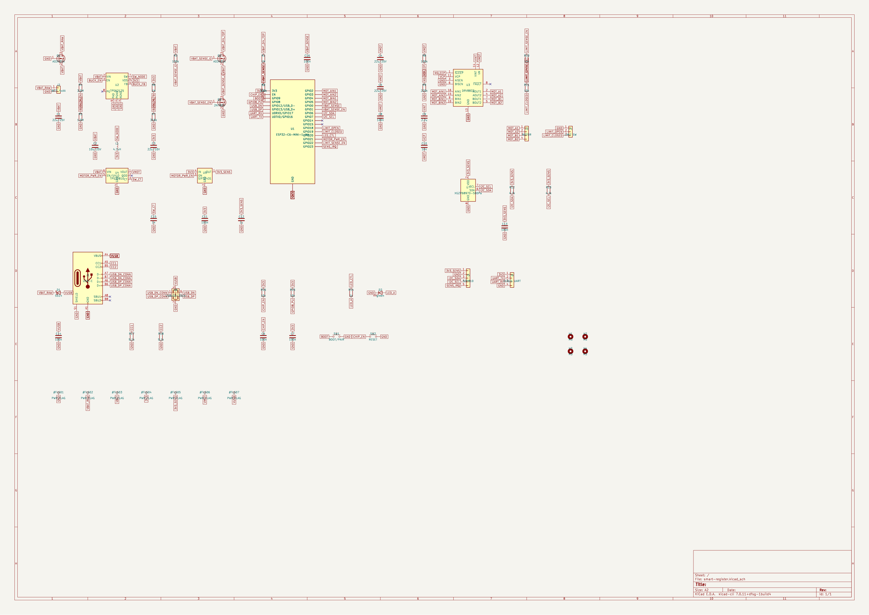
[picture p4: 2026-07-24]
docs/img/schematic.png

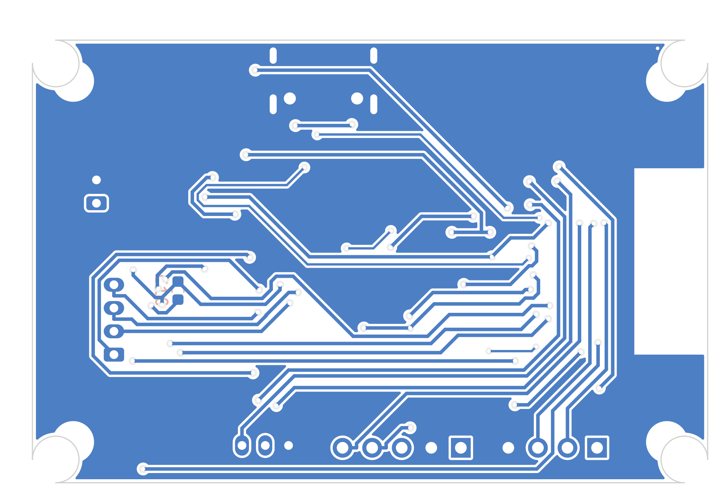
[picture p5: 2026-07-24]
docs/img/pcb_back.png

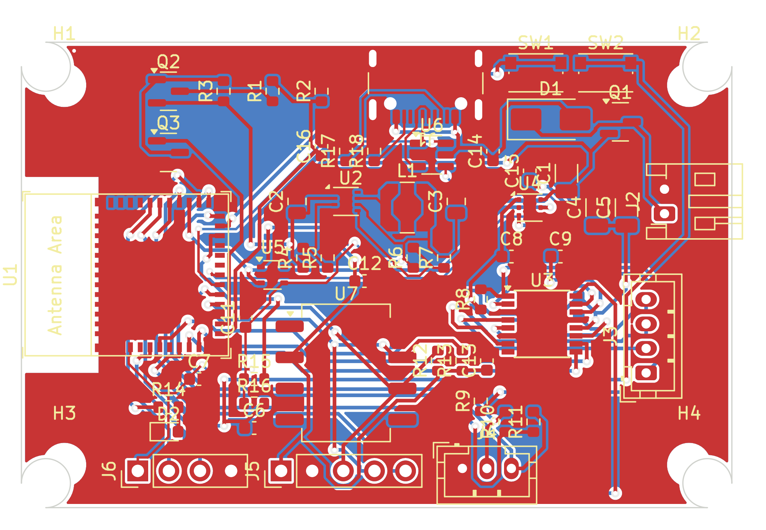
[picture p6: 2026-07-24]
docs/img/pcb_both.png

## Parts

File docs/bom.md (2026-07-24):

# Bill of Materials

Everything needed to build **one** smart register, plus a one-time dev-bench
section for firmware bring-up. Prices are mid-2026 estimates in USD at qty 1;
order chips by **manufacturer part number (MPN)** at Digi-Key/Mouser (search
the MPN directly), or by LCSC number if you have JLCPCB assemble the board.

> **Order of operations:** buy the *dev bench* section first, validate the
> firmware end-to-end on breakouts, **then** order the custom PCB and its
> components. The PCB is validation, not the critical path.

## A. Custom PCB — semiconductors & modules

| # | Part | MPN | Package | Qty | Est. $ | Notes |
|---|---|---|---|---|---|---|
| A1 | Zigbee module | ESP32-C6-MINI-1-N4 | SMD module | 1 | 3.20 | PCB antenna; keep-out zone per Espressif AN |
| A2 | Buck converter 3.3 V | TPS62125DSGR | WSON-8 2×2 | 1 | 1.60 | 3–17 V in, Iq ≈ 13 µA, 300 mA |
| A3 | Stepper driver | DRV8833PWPR | HTSSOP-16 | 1 | 1.80 | Dual H-bridge; drives bipolar-modified 28BYJ-48 |
| A4 | Load switch (motor rail) | TPS22810DRVR | WSON-6 2×2 | 1 | 0.70 | 18 V rated — a 5.5 V-max part (TPS22919/SiP32431) cannot sit on the 7.2 V fresh pack |
| A4b | Load switch (sensor 3.3 V rail) | SIP32431DR3-T1GE3 | SC70-6 | 1 | 0.50 | 10 nA leakage; same MOTOR_PWR_EN control line |
| A5 | Reverse-polarity P-FET | AO3401A | SOT-23 | 1 | 0.30 | ±12 V Vgs handles the 7.2 V fresh pack; also battery-sense high-side (qty 2 total) |
| A6 | Battery-sense P-FET | AO3401A | SOT-23 | 1 | 0.30 | (counted with A5 in the schematic as Q1/Q2) |
| A7 | N-FET (divider gate drive) | 2N7002-7-F | SOT-23 | 1 | 0.10 | |
| A8 | Pressure sensor (on-board default) | **XGZP6897D (±500 Pa, I2C)** | DIP-8 w/ ports | 1 | 4.00 | Fitted on the board (`U7`); needs firmware auto-zero (implemented) |
| A8b | *Premium alternate* | SDP810-500PA | barbed module | (1) | 28.00 | Connects to the 5-pin remote-sensor header `J5` instead of fitting U7; best zero-point stability |
| A9 | USB ESD protection | USBLC6-2SC6 | SOT-23-6 | 1 | 0.40 | |
| A10 | Status LED | 0603 green (e.g. 150060GS75000) | 0603 | 1 | 0.10 | |
| A11 | USB bench-power Schottky | SS14 | SMA | 1 | 0.15 | Feeds VBAT_RAW from USB 5 V (pre-FET, cannot charge the cells) |

## B. Custom PCB — passives & electromechanical

| # | Part | Value / MPN | Package | Qty | Est. $ | Notes |
|---|---|---|---|---|---|---|
| B1 | Buck inductor | 4.7 µH, LPS4018-472MRB | 4×4 mm | 1 | 0.80 | Per TPS62125 datasheet app |
| B2 | Input caps | 22 µF 25 V X5R | 1206 | 2 | 0.40 | One at pack input, one at buck VIN |
| B3 | Output cap | 22 µF 10 V X5R | 0805 | 1 | 0.20 | Buck VOUT |
| B4 | Motor rail bulk cap | 100 µF 16 V (poly or MLCC ×2) | — | 1 | 0.50 | Absorbs stepper current steps |
| B5 | Decoupling | 100 nF X7R | 0603 | 8 | 0.20 | Every IC |
| B6 | Misc caps | 1 µF, 10 µF | 0603 | 4 | 0.20 | Sensor + module decoupling |
| B7 | Divider resistors | 1 MΩ + 330 kΩ 1 % | 0603 | 2 | 0.10 | VBAT sense |
| B8 | I2C pull-ups | 4.7 kΩ | 0603 | 2 | 0.05 | To switched rail (no standby drain) |
| B9 | Misc resistors | 100 Ω, 1 kΩ, 10 kΩ, 100 kΩ | 0603 | ~12 | 0.20 | Gates, LED, straps, button pull |
| B10 | USB-C receptacle | GCT USB4105-GF-A | 16-pin SMD | 1 | 0.90 | Flash/debug via USB-Serial-JTAG |
| B11 | Tactile switches (BOOT, RST) | C&K KMR221GLFS | SMD | 2 | 0.60 | BOOT doubles as pair/factory-reset |
| B12 | Battery connector | JST S2B-PH-K-S | PH 2-pin RA | 1 | 0.20 | Mates battery holder pigtail |
| B13 | Motor connector | JST B4B-PH-K-S | PH 4-pin | 1 | 0.25 | Bipolar-modified 28BYJ-48 (4 wires) |
| B14 | Limit-switch connector | JST B3B-PH-K-S | PH 3-pin | 1 | 0.20 | Common bias + 2 switch lines |
| B15 | Debug header | 2.54 mm 1×4 | TH | 1 | 0.10 | UART TX/RX/GND/3V3 |

## C. PCB fabrication

| # | Item | Qty | Est. $ | Notes |
|---|---|---|---|---|
| C1 | 2-layer PCB fab (JLCPCB/PCBWay), 5 pcs min | 1 order | 10–15 | Upload `hardware/pcb/fab/` gerbers; 1.6 mm FR4, HASL or ENIG |
| C2 | (Optional) JLCPCB assembly, 2 boards | 1 order | 30–60 | Or hand-solder; everything is 0603+ except the WSON buck (use hot air/paste) |

## D. Electromechanical (per register)

| # | Part | MPN / spec | Qty | Est. $ | Notes |
|---|---|---|---|---|---|
| D1 | Geared stepper | 28BYJ-48, **5 V** version | 1 | 2.50 | Bipolar mod: open the blue cap, cut the center-tap trace, ignore the red wire (documented in assembly.md) |
| D2 | Limit switches | Omron D2F-L (lever) or SS-5GL | 2 | 3.00 | Subminiature snap-action, lever type |
| D3 | Battery holder | 4× AA, wire leads (Keystone 2478 or equiv.) | 1 | 2.50 | Fit JST-PH pigtail to leads |
| D4 | Batteries | Energizer L91 Ultimate Lithium AA | 4 | 8.00 | LiFeS2 — do **not** substitute alkaline (sag + cold) |
| D5 | Silicone tubing | 2 mm ID × 4 mm OD, ~20 cm | 1 | 1.00 | Pressure ports → sensor barbs |
| D6 | Heat-set inserts | M3 × 5.7 (Ruthex/CNC-Kitchen style) | ~10 | 1.50 | Frame + e-bay assembly |
| D7 | Screws | M3 × 8 pan head | ~10 | 0.50 | |
| D8 | Screws (motor) | M4 × 6 or M3 w/ printed adapter | 2 | 0.20 | 28BYJ-48 flange holes are 4.2 mm |
| D9 | Hookup wire | 26–28 AWG silicone, ~1 m | — | 0.50 | Switch + motor leads |
| D10 | Print filament | **PETG minimum, ASA recommended**, ~350 g | — | 7.00 | Supply air hits 55–65 °C; PLA will creep. Faceplate can be anything |

## E. Dev bench (one-time, for firmware bring-up — buy first)

| # | Part | MPN / spec | Qty | Est. $ | Notes |
|---|---|---|---|---|---|
| E1 | Dev board | ESP32-C6-DevKitC-1-N8 | 1 | 9.00 | Same pin map as rev A via Kconfig |
| E2 | Stepper + driver kit | 28BYJ-48 + ULN2003 board | 1 | 3.00 | First motion tests (unipolar, before the bipolar mod) |
| E3 | DRV8833 breakout | Adafruit 3297 or generic | 1 | 5.00 | Validates the bipolar mod + final drive scheme |
| E4 | Pressure sensor | SDP810-500PA (same as A8) | 1 | 28.00 | Moves to the first PCB later |
| E5 | Microswitches | same as D2 | 2 | 3.00 | |
| E6 | Battery holder + 4× L91 | same as D3/D4 | 1 | 10.50 | For real power-budget measurements |
| E7 | Breadboard + jumpers | generic | 1 | 8.00 | |
| E8 | (If needed) Zigbee coordinator | Sonoff ZBDongle-E or SLZB-06 | 1 | 20–30 | Skip if your HA already has Zigbee |
| E9 | (Recommended) µA-capable meter | e.g. Nordic PPK2 | 1 | 90.00 | Optional but the only way to verify the 150 µA budget |

## Totals (approximate)

| Scope | Est. cost |
|---|---|
| One register, SDP810 build (A+B+D, excl. fab amortization) | **~$65** |
| One register, XGZP6897D cost-down build | **~$40** |
| PCB fab + assembly, amortized over 5 boards | ~$5–15/board |
| Dev bench (one-time, no coordinator/PPK2) | ~$65 |

Multi-register houses: parts A+B+D scale per register; C amortizes.

## Substitution notes

- **SDP810 → SDP31/SDP32** (SMD): same sensing core, needs a printed manifold
  instead of barbs; consider for a later rev.
- **28BYJ-48 → 35BYJ-46 (12 V run at pack voltage)**: fallback if vane torque
  is marginal (mount is parametric in `cad/smart_register/params.py`).
- Do **not** substitute the buck with a TPS62840-class part: its 6.5 V max
  input is below the 7.2 V fresh-pack voltage.

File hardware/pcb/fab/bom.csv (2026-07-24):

Comment | Designator | Footprint | MPN | Qty
22u/25V | C1,C4,C5 | C_1206_3216Metric | GRM31CR61E226KE15 | 3
10n | C10 | C_0603_1608Metric | CL10B103KB8NNNC | 1
1u | C12 | C_0603_1608Metric | CL10A105KB8NNNC | 1
1n | C15 | C_0603_1608Metric | CL10B102KB8NNNC | 1
10u/25V | C2 | C_0805_2012Metric | GRM21BR61E106KA73 | 1
22u/10V | C3 | C_0805_2012Metric | GRM21BR61A226ME44 | 1
100n | C11,C13,C14,C16,C6,C7,C8 | C_0603_1608Metric | CL10B104KB8NNNC | 7
2.2u | C9 | C_0603_1608Metric | CL10A225KP8NNNC | 1
SS14 | D1 | D_SMA | SS14 | 1
green | D2 | LED_0603_1608Metric | 150060GS75000 | 1
USB-C | J1 | USB_C_Receptacle_GCT_USB4105-xx-A_16P_TopMnt_Horizontal | GCT USB4105-GF-A | 1
BATT 4xAA | J2 | JST_PH_S2B-PH-K_1x02_P2.00mm_Horizontal | JST S2B-PH-K-S | 1
MOTOR | J3 | JST_PH_B4B-PH-K_1x04_P2.00mm_Vertical | JST B4B-PH-K-S | 1
LIMIT SW | J4 | JST_PH_B3B-PH-K_1x03_P2.00mm_Vertical | JST B3B-PH-K-S | 1
SDP810 | J5 | PinHeader_1x05_P2.54mm_Vertical | header 1x5 | 1
DEBUG UART | J6 | PinHeader_1x04_P2.54mm_Vertical | header 1x4 | 1
4.7uH | L1 | L_Coilcraft_LPS4018 | LPS4018-472MRB | 1
AO3401A | Q1,Q2 | SOT-23 | AO3401A | 2
2N7002 | Q3 | SOT-23 | 2N7002-7-F | 1
1M | R1,R6 | R_0603_1608Metric | RC0603FR-071ML | 2
10k | R10,R11,R15,R16 | R_0603_1608Metric | RC0603FR-0710KL | 4
4.7k | R12,R13 | R_0603_1608Metric | RC0603FR-074K7L | 2
1k | R14 | R_0603_1608Metric | RC0603FR-071KL | 1
5.1k | R17,R18 | R_0603_1608Metric | RC0603FR-075K1L | 2
330k | R2 | R_0603_1608Metric | RC0603FR-07330KL | 1
100k | R3,R8 | R_0603_1608Metric | RC0603FR-07100KL | 2
3.0M | R4 | R_0603_1608Metric | RC0603FR-073ML | 1
1.0M | R5 | R_0603_1608Metric | RC0603FR-071ML | 1
316k | R7 | R_0603_1608Metric | RC0603FR-07316KL | 1
220k | R9 | R_0603_1608Metric | RC0603FR-07220KL | 1
BOOT/PAIR | SW1 | SW_Push_1P1T_NO_CK_KMR2 | KMR221GLFS | 1
RESET | SW2 | SW_Push_1P1T_NO_CK_KMR2 | KMR221GLFS | 1
ESP32-C6-MINI-1-N4 | U1 | ESP32-C6-MINI-1 | ESP32-C6-MINI-1-N4 | 1
TPS62125 | U2 | WSON-8-1EP_2x2mm_P0.5mm_EP0.9x1.6mm | TPS62125DSGR | 1
DRV8833 | U3 | HTSSOP-16-1EP_4.4x5mm_P0.65mm_EP3.4x5mm | DRV8833PWPR | 1
TPS22810 | U4 | WSON-6-1EP_2x2mm_P0.65mm_EP1x1.6mm | TPS22810DRVR | 1
SiP32431 | U5 | SOT-363_SC-70-6 | SIP32431DR3-T1GE3 | 1
USBLC6-2SC6 | U6 | SOT-23-6 | USBLC6-2SC6 | 1
XGZP6897D-500Pa | U7 | CFSensor_XGZP6897x | XGZP6897D (+-500Pa I2C) | 1

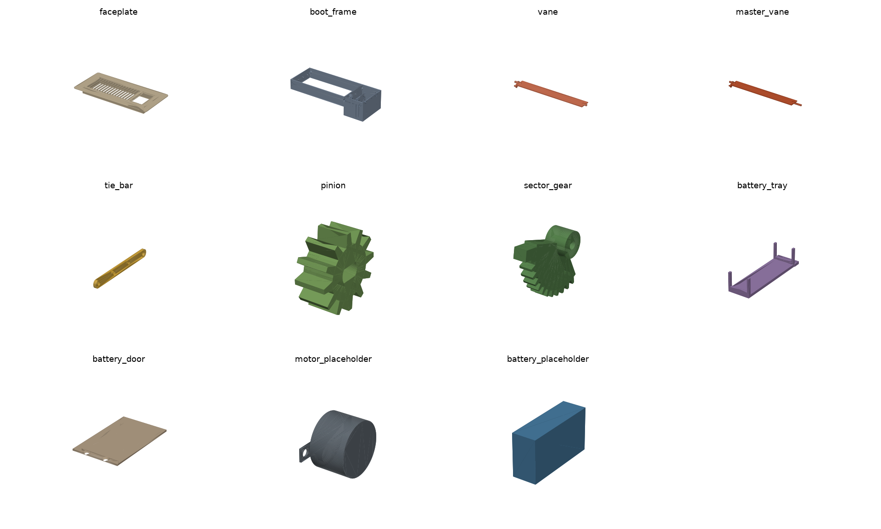
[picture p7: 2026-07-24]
docs/img/parts_grid.png

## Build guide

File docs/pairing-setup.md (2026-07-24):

# Pairing & Home Assistant Setup

How to get an SR-4x10 register from the box into Home Assistant, with either
Zigbee2MQTT (recommended — full feature set) or ZHA. Device background is in
[architecture.md](architecture.md); the one fact worth internalizing before
you start: this is a **sleepy end device**. It is asleep almost all the time
and only listens for ~5 s windows. Every "it's not responding" problem in this
guide comes back to that.

Everywhere the UI shows a position, **100 = fully open = maximum airflow**.

## 1. Zigbee2MQTT (recommended)

### 1.1 Install the external converter

Copy the converter into the `external_converters` folder inside your
Zigbee2MQTT data directory (the folder that contains `configuration.yaml`;
create `external_converters` if it doesn't exist):

```
# Home Assistant add-on install:
/config/zigbee2mqtt/external_converters/smart_register.mjs

# Generic install:
<z2m-data-dir>/external_converters/smart_register.mjs
```

The file is [`homeassistant/zigbee2mqtt/smart_register.mjs`](../homeassistant/zigbee2mqtt/smart_register.mjs)
in this repo. Zigbee2MQTT 2.x loads everything in that folder automatically on
startup — restart Zigbee2MQTT and check the log for a line loading the
converter (and no red errors mentioning `smart_register`).

> Z2M 1.x note: older versions instead require listing the file under
> `external_converters:` in `configuration.yaml`. Use Z2M 1.40+ or 2.x; the
> converter uses the modern extend API.

### 1.2 Pair

1. In Zigbee2MQTT, enable **Permit join** (ideally on the router nearest the
   register's final location — sleepy devices keep the parent they join
   through).
2. Insert batteries. A fresh (never-joined or factory-reset) unit starts
   network steering on its own.
3. Already-provisioned unit, or nothing happens: **hold the BOOT button for
   5 seconds**. The status LED starts the Identify blink and the device
   factory-resets and begins searching for a network.
4. Watch the Z2M log: `joined`, then `interview started`.

**Sleepy-device gotcha — keep it awake during the interview.** The interview
(reading endpoints, clusters, Basic strings) needs many round-trips, and the
device sleeps between 5 s polls. It fast-polls for a while after joining, but
if the interview stalls, **press the BOOT button briefly (short press)** —
that wakes it and opens a fast-poll window so the interview can proceed. It is
normal for the interview to fail once and succeed on retry (Z2M retries by
itself; you can also force it via *Reconfigure* on the device page). Keep the
device physically near a router (or the coordinator) for first pairing.

When the interview finishes the device shows up as **OpenRegister SR-4x10**.
If it instead shows as "unsupported", the external converter did not load —
recheck step 1.1.

### 1.3 What you get

| Entity | Type | Notes |
|---|---|---|
| `cover.<name>` | cover (position) | 100 = open = airflow, 0 = closed |
| `sensor.<name>_pressure` | sensor, Pa | duct static pressure, 1 Pa resolution (from `ScaledValue`) |
| `sensor.<name>_battery` | sensor, % | daily report; loaded-voltage based, honest for lithium AA |
| `sensor.<name>_voltage` | sensor, mV | battery voltage |
| `binary_sensor.<name>_failsafe_tripped` | binary_sensor (diagnostic) | local fail-open is active |
| `number.<name>_failsafe_threshold_pa` | number (config) | 50–500 Pa, step 5, default **150** |
| `number.<name>_failsafe_clear_hysteresis_pa` | number (config) | 5–100 Pa, default **30** |
| `sensor.<name>_last_trip_pressure_pa` | sensor (diagnostic) | pressure at last trip |
| `switch.<name>_auto_clear_enable` | switch (config) | ON = auto-resume after pressure recovers |
| `sensor.<name>_fault_code` | sensor (diagnostic) | `none` / `homing_timeout` / `stall` / `sensor_fail` |

Writes to the config entities (threshold, hysteresis, auto-clear) are
delivered on the device's next poll — allow up to ~5 s, and don't be surprised
that the UI value confirms only after the following read-back.

## 2. ZHA alternative

ZHA handles the cover, battery and a coarse (hPa) pressure sensor natively.
The custom fail-safe cluster needs the quirk.

1. Copy [`homeassistant/zha/smart_register_quirk.py`](../homeassistant/zha/smart_register_quirk.py)
   to a folder in your HA config, e.g. `/config/custom_zha_quirks/`.
2. Point ZHA at it in `configuration.yaml`:

   ```yaml
   zha:
     custom_quirks_path: /config/custom_zha_quirks/
   ```

3. Restart Home Assistant, then pair as in 1.2 (Settings → Devices → ZHA →
   Add device). The same BOOT-button rules apply.
4. Verify on the device page that the quirk is applied (Device info →
   "Quirk"). You get the same fail-safe entities as in the Z2M table above,
   plus a "Duct pressure" sensor in real Pa from `ScaledValue`.

If the device paired *before* the quirk was installed, remove and re-pair it
(or reconfigure) so the quirk's signature match and reporting setup apply.

## 3. Blueprints

Import both blueprints (Settings → Automations & Scenes → Blueprints →
Import blueprint, or copy the files):

```
config/blueprints/automation/openregister/room_register_control.yaml
config/blueprints/automation/openregister/pressure_floor_guard.yaml
```

Sources: [`homeassistant/blueprints/`](../homeassistant/blueprints/).

### 3.1 Per-room setup — one automation per room

For **each** room with a register, create an automation from
**"OpenRegister: room register control (proportional)"**:

1. **Room temperature sensor** — any temperature sensor in that room.
2. **Target temperature entity** — an `input_number` helper you create per
   room (e.g. `input_number.bedroom_setpoint`, 15–28 °C, step 0.5), **or**
   set the optional **Climate entity** to your thermostat to reuse its
   setpoint (the climate entity wins while it is available).
3. **Register cover entity** — that room's SR-4x10.
4. **Heat/cool mode** — `heat` opens the register when the room is too cold,
   `cool` when it is too warm. If your system switches seasonally, either
   flip this input twice a year or create two automations and enable the
   right one.
5. Leave the tuning inputs at their defaults to start: proportional band
   2.0 °C, deadband 0.3 °C, update every 5 min, step 10 %, minimum
   position 0 %.

Battery notes: the automation only moves the register when the commanded
change is ≥ one quantization step, so a well-tuned room settles and stops
moving. If a register is moving many times per hour, widen the proportional
band or increase the step.

### 3.2 Whole-system setup — exactly one pressure floor guard

Create **one** automation from **"OpenRegister: pressure floor guard"** for
the whole duct system:

- **Register cover entities** — every SR-4x10 on the system.
- **Minimum total open floor** — default 150 (= 1.5 registers-worth open).
  Rule of thumb: never let the room automations close more area than your
  blower tolerates; if unsure, keep ≥ 30–40 % of total register area open.
- **Fail-safe tripped sensors** — the registers' `failsafe_tripped`
  binary sensors, for trip notifications.
- **Notify service** — e.g. `notify.mobile_app_yourphone`.

The guard treats `unavailable`/`unknown` registers as **closed** (a
dead-battery register can't fail open — see architecture.md failure modes),
so a register dropping offline can legitimately cause the guard to open other
registers. That is by design.

### 3.3 Tuning threshold & hysteresis

The device-local fail-safe is the last line of defense; the numbers live on
the device (NVS) and work with HA completely offline.

1. With all registers open and the blower running, note the typical duct
   pressure (the `pressure` sensor).
2. Close registers (temporarily lower the guard floor if needed) until you
   reach the *most closed* configuration you would ever allow, note the
   pressure.
3. Set **failsafe_threshold_pa** comfortably above that worst-case normal
   pressure but below what your blower/ducts tolerate. Default **150 Pa**
   suits typical residential systems; static-pressure-rated ECM blowers may
   allow more.
4. **failsafe_clear_hysteresis_pa** (default **30 Pa**) sets how far pressure
   must fall below the threshold before the fail-safe clears. If a register
   trips and clears repeatedly (flapping) as the blower cycles, increase it.
5. **auto_clear_enable** ON means the register returns to its commanded
   position by itself once pressure recovers; OFF latches the fail-open until
   you toggle/clear from HA — useful while diagnosing why it tripped.

After a trip, `last_trip_pressure_pa` tells you how bad it actually got.

## 4. Troubleshooting

| Symptom | Cause | Fix |
|---|---|---|
| Interview never completes / device stuck "interviewing" | Sleepy device slept through the interview | Short-press BOOT to wake it (fast-poll window), retry the interview; pair close to a router |
| "Failed to configure" in Z2M / entities exist but never update | Configure (bind + reporting setup) ran while the device was asleep | Short-press BOOT, then *Reconfigure* on the device page in Z2M/ZHA |
| Position/pressure updates stop entirely | Reporting was never configured, or device re-joined through a different parent | Reconfigure (see above); check LQI/parent in the network map |
| Cover position looks inverted (100 shows as closed) | Outdated or missing external converter (raw ZCL lift is inverted by design: lift 100 = closed) | Confirm `smart_register.mjs` is loaded and current; the converter maps lift → HA position so 100 = open. Do **not** "fix" with an HA template inversion |
| Device shows as unsupported (Z2M) | External converter not loaded | Check `external_converters/` path and Z2M startup log, restart Z2M |
| Fail-safe entities missing (ZHA) | Quirk not applied | Check `custom_quirks_path`, restart HA, re-pair or reconfigure the device |
| Writing threshold/hysteresis seems to do nothing | Write is queued until the next ~5 s poll; UI confirms on read-back | Wait a few seconds; short-press BOOT to force it through immediately |
| Fail-safe reads/writes fail with `UNSUPPORTED_ATTRIBUTE` | Manufacturer-code mismatch between firmware and converter/quirk (cluster 0xFC00, mfr code 0x131B) | Update converter/quirk and firmware to matching releases |
| Register won't move, `fault_code` ≠ `none` | Homing timeout / stall / pressure-sensor fault; device refuses normal moves | Check for vane obstruction, then power-cycle (re-homes on boot). `sensor_fail` with a working duct: check the sensor tubing |
| Frequent trip/clear cycling | Threshold too close to normal operating pressure | Raise `failsafe_threshold_pa` or increase `failsafe_clear_hysteresis_pa` |
| Battery draining fast | Automations commanding many small moves | Increase position step / proportional band in the room blueprint; check update interval; verify pressure reporting isn't flapping around ±10 Pa |

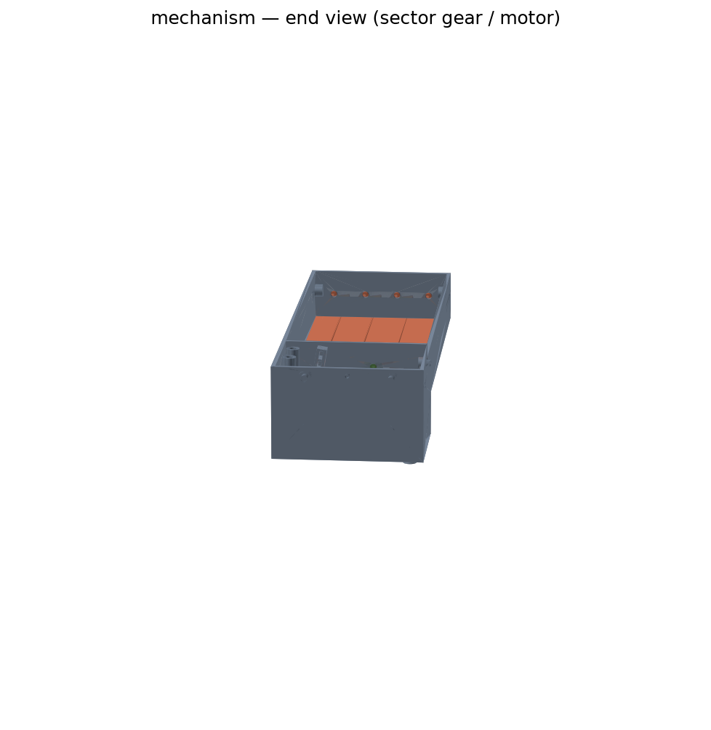
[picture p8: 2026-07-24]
docs/img/assembly_mechanism_end.png

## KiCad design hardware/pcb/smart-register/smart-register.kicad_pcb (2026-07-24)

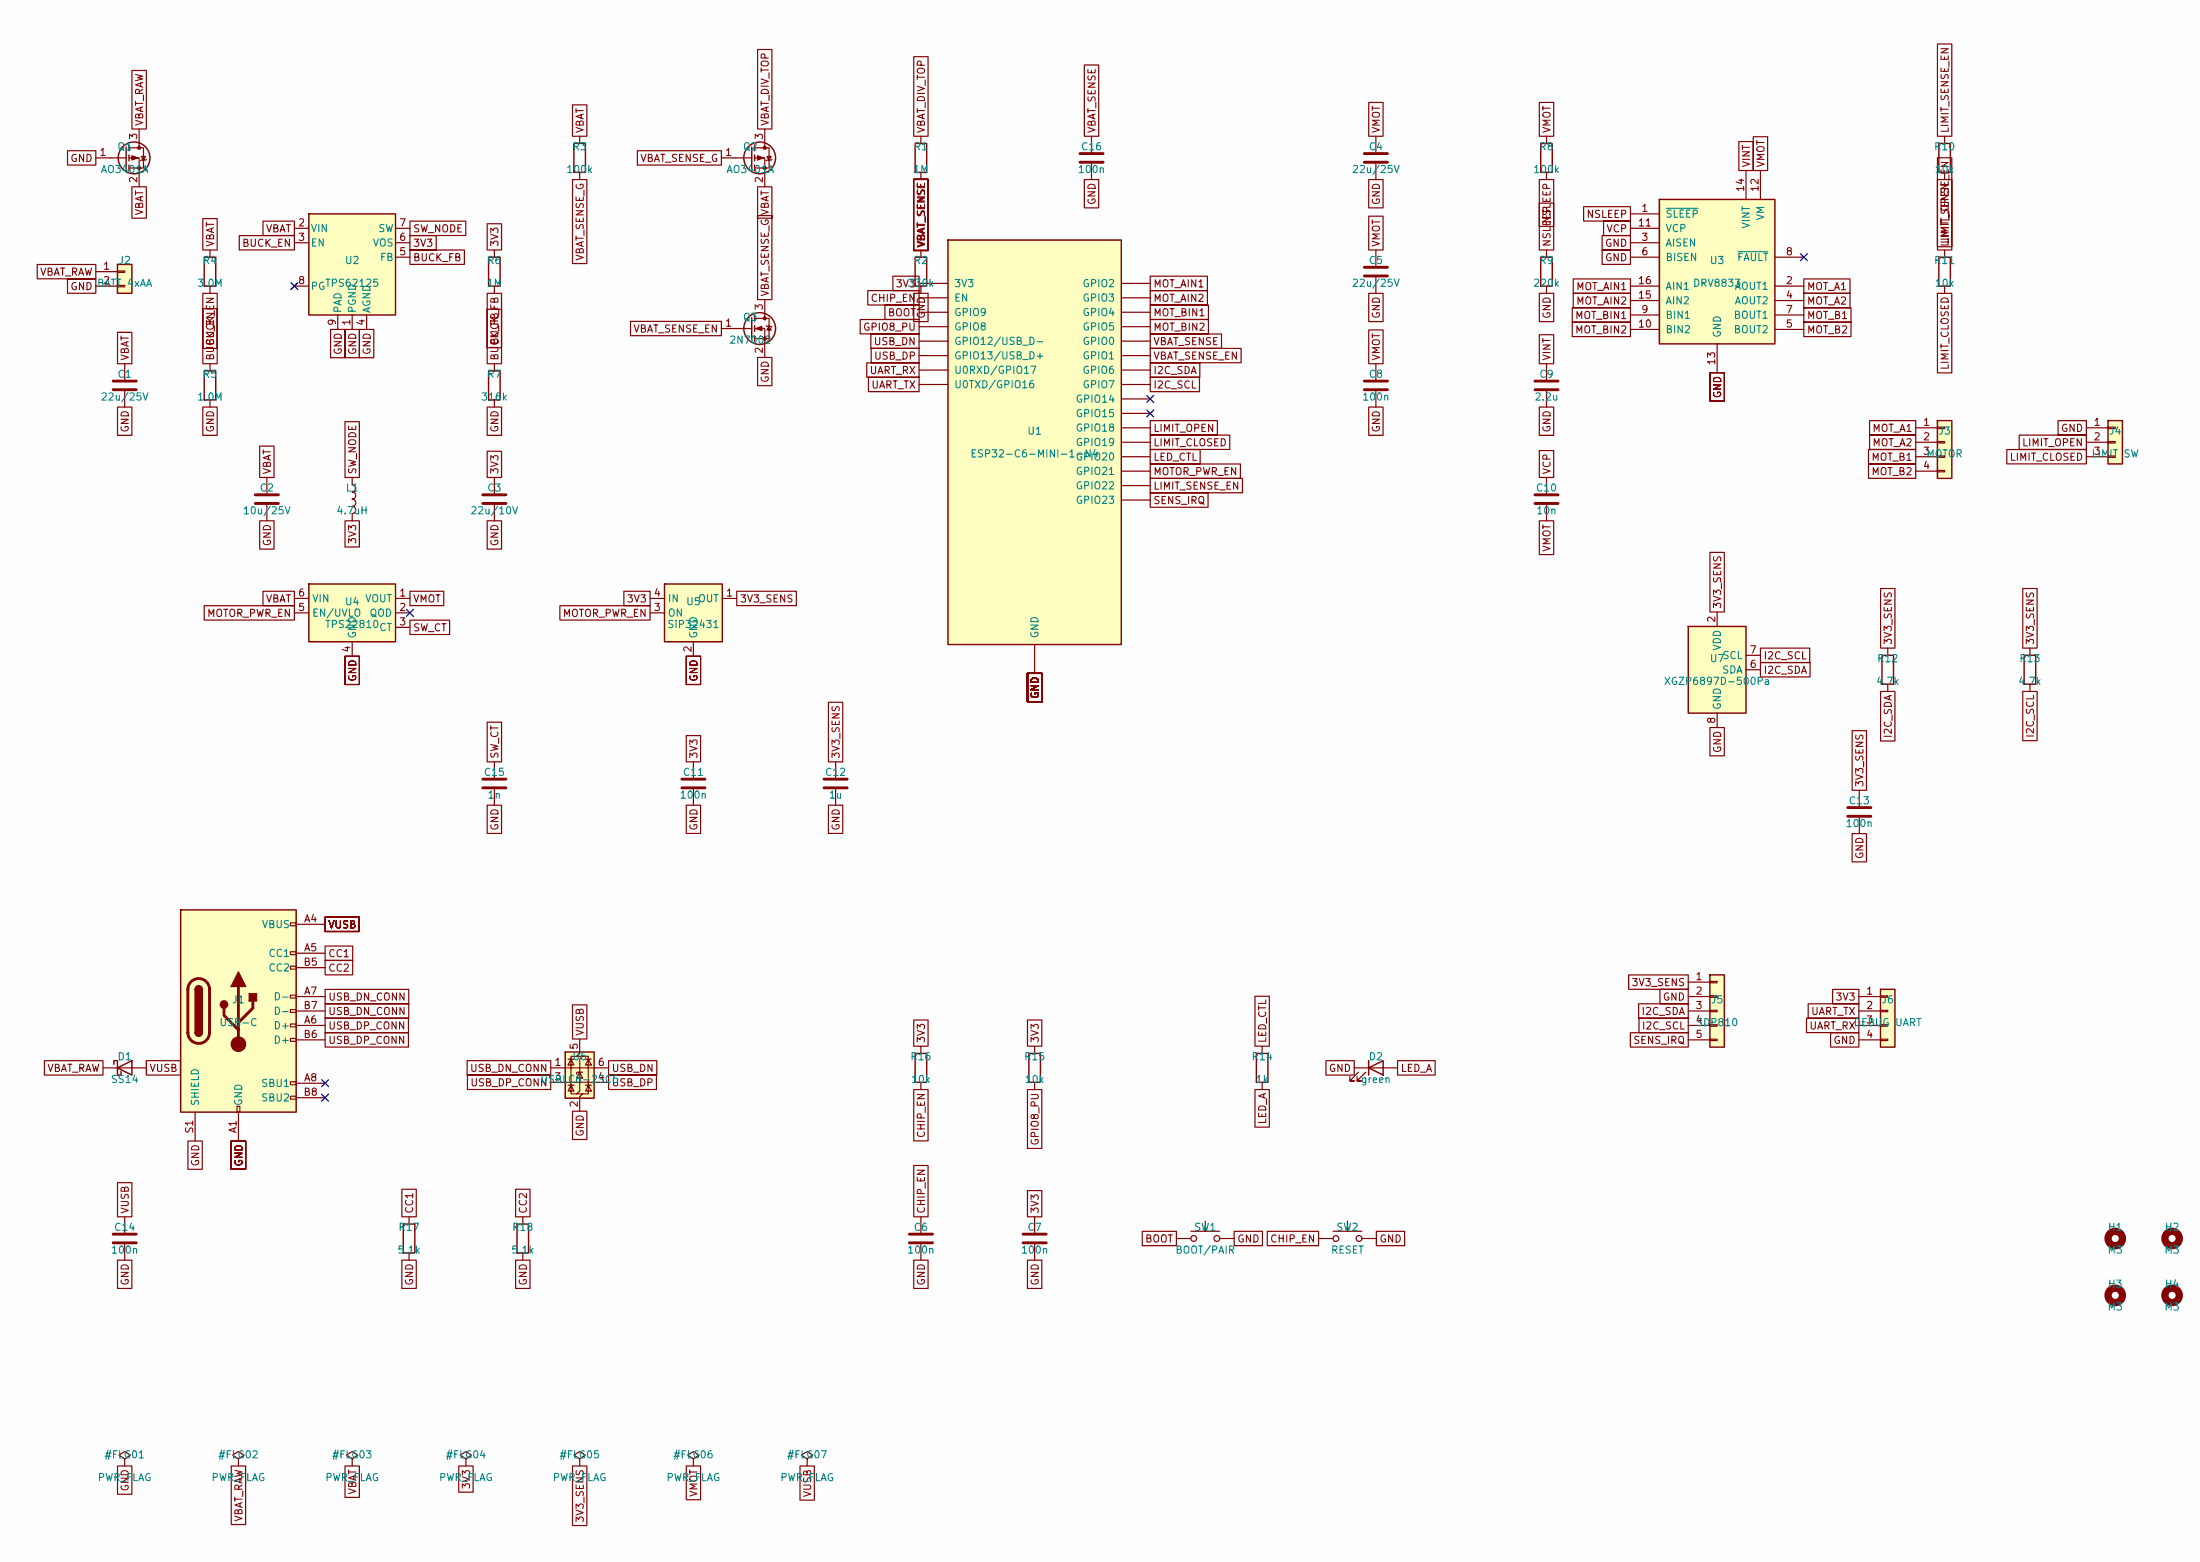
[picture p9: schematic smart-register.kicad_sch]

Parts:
C1, C4, C5: 22u/25V; C_1206_3216Metric; MPN GRM31CR61E226KE15
C2: 10u/25V; C_0805_2012Metric; MPN GRM21BR61E106KA73
C3: 22u/10V; C_0805_2012Metric; MPN GRM21BR61A226ME44
C6, C7, C8, C11, C13, C14, C16: 100n; C_0603_1608Metric; MPN CL10B104KB8NNNC
C9: 2.2u; C_0603_1608Metric; MPN CL10A225KP8NNNC
C10: 10n; C_0603_1608Metric; MPN CL10B103KB8NNNC
C12: 1u; C_0603_1608Metric; MPN CL10A105KB8NNNC
C15: 1n; C_0603_1608Metric; MPN CL10B102KB8NNNC
D1: SS14; D_SMA; MPN SS14
D2: green; LED_0603_1608Metric; MPN 150060GS75000
H1, H2, H3, H4: M3; MountingHole_3.2mm_M3
J1: USB-C; USB_C_Receptacle_GCT_USB4105-xx-A_16P_TopMnt_Horizontal; MPN GCT USB4105-GF-A
J2: BATT 4xAA; JST_PH_S2B-PH-K_1x02_P2.00mm_Horizontal; MPN JST S2B-PH-K-S
J3: MOTOR; JST_PH_B4B-PH-K_1x04_P2.00mm_Vertical; MPN JST B4B-PH-K-S
J4: LIMIT SW; JST_PH_B3B-PH-K_1x03_P2.00mm_Vertical; MPN JST B3B-PH-K-S
J5: SDP810; PinHeader_1x05_P2.54mm_Vertical; MPN header 1x5
J6: DEBUG UART; PinHeader_1x04_P2.54mm_Vertical; MPN header 1x4
L1: 4.7uH; L_Coilcraft_LPS4018; MPN LPS4018-472MRB
Q1, Q2: AO3401A; SOT-23; MPN AO3401A
Q3: 2N7002; SOT-23; MPN 2N7002-7-F
R1, R6: 1M; R_0603_1608Metric; MPN RC0603FR-071ML
R2: 330k; R_0603_1608Metric; MPN RC0603FR-07330KL
R3, R8: 100k; R_0603_1608Metric; MPN RC0603FR-07100KL
R4: 3.0M; R_0603_1608Metric; MPN RC0603FR-073ML
R5: 1.0M; R_0603_1608Metric; MPN RC0603FR-071ML
R7: 316k; R_0603_1608Metric; MPN RC0603FR-07316KL
R9: 220k; R_0603_1608Metric; MPN RC0603FR-07220KL
R10, R11, R15, R16: 10k; R_0603_1608Metric; MPN RC0603FR-0710KL
R12, R13: 4.7k; R_0603_1608Metric; MPN RC0603FR-074K7L
R14: 1k; R_0603_1608Metric; MPN RC0603FR-071KL
R17, R18: 5.1k; R_0603_1608Metric; MPN RC0603FR-075K1L
SW1: BOOT/PAIR; SW_Push_1P1T_NO_CK_KMR2; MPN KMR221GLFS
SW2: RESET; SW_Push_1P1T_NO_CK_KMR2; MPN KMR221GLFS
U1: ESP32-C6-MINI-1-N4; ESP32-C6-MINI-1; MPN ESP32-C6-MINI-1-N4
U2: TPS62125; WSON-8-1EP_2x2mm_P0.5mm_EP0.9x1.6mm; MPN TPS62125DSGR
U3: DRV8833; HTSSOP-16-1EP_4.4x5mm_P0.65mm_EP3.4x5mm; MPN DRV8833PWPR
U4: TPS22810; WSON-6-1EP_2x2mm_P0.65mm_EP1x1.6mm; MPN TPS22810DRVR
U5: SiP32431; SOT-363_SC-70-6; MPN SIP32431DR3-T1GE3
U6: USBLC6-2SC6; SOT-23-6; MPN USBLC6-2SC6
U7: XGZP6897D-500Pa; CFSensor_XGZP6897x; MPN XGZP6897D (+-500Pa I2C)

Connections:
3V3: C3.1, C7.1, C11.1, J6.1, L1.2, R6.1, R15.1, R16.1, U1.3 (3V3), U2.6 (VOS), U5.4 (IN)
3V3_SENS: C12.1, C13.1, J5.1, R12.1, R13.1, U5.1 (OUT), U7.2 (VDD)
BOOT: SW1.1, U1.23 (GPIO9)
BUCK_EN: R4.2, R5.1, U2.3 (EN)
BUCK_FB: R6.2, R7.1, U2.5 (FB)
CC1: J1.A5 (CC1), R17.1
CC2: J1.B5 (CC2), R18.1
CHIP_EN: C6.1, R16.2, SW2.1, U1.8 (EN)
GND: C1.2, C2.2, C3.2, C4.2, C5.2, C6.2, C7.2, C8.2, C9.2, C11.2, C12.2, C13.2, C14.2, C15.2, C16.2, D2.1 (K), J1.A1 (GND), J1.A12 (GND), J1.B1 (GND), J1.B12 (GND), J1.S1 (SHIELD), J2.2, J4.1, J5.2, J6.4, Q1.1 (G), Q3.2 (S), R2.2, R5.2, R7.2, R9.2, R17.2, R18.2, SW1.2, SW2.2, U1.1 (GND), U1.2 (GND), U1.11 (GND), U1.14 (GND), U1.34 (NC), U1.36 (GND), U1.37 (GND), U1.38 (GND), U1.39 (GND), U1.40 (GND), U1.41 (GND), U1.42 (GND), U1.43 (GND), U1.44 (GND), U1.45 (GND), U1.46 (GND), U1.47 (GND), U1.48 (GND), U1.49 (GND), U1.50 (GND), U1.51 (GND), U1.52 (GND), U1.53 (GND), U2.1 (PGND), U2.4 (AGND), U2.9 (PAD), U3.3 (AISEN), U3.6 (BISEN), U3.13 (GND), U3.17 (GND), U4.4 (GND), U4.7 (GND), U5.2 (GND), U5.5 (GND), U6.2 (GND), U7.8 (GND)
GPIO8_PU: R15.2, U1.22 (GPIO8)
I2C_SCL: J5.4, R13.2, U1.16 (GPIO7), U7.7 (SCL)
I2C_SDA: J5.3, R12.2, U1.15 (GPIO6), U7.6 (SDA)
LED_A: D2.2 (A), R14.2
LED_CTL: R14.1, U1.26 (GPIO20)
LIMIT_CLOSED: J4.3, R11.2, U1.25 (GPIO19)
LIMIT_OPEN: J4.2, R10.2, U1.24 (GPIO18)
LIMIT_SENSE_EN: R10.1, R11.1, U1.28 (GPIO22)
MOTOR_PWR_EN: U1.27 (GPIO21), U4.5 (EN/UVLO), U5.3 (ON)
MOT_A1: J3.1, U3.2 (AOUT1)
MOT_A2: J3.2, U3.4 (AOUT2)
MOT_AIN1: U1.5 (GPIO2), U3.16 (AIN1)
MOT_AIN2: U1.6 (GPIO3), U3.15 (AIN2)
MOT_B1: J3.3, U3.7 (BOUT1)
MOT_B2: J3.4, U3.5 (BOUT2)
MOT_BIN1: U1.9 (GPIO4), U3.9 (BIN1)
MOT_BIN2: U1.10 (GPIO5), U3.10 (BIN2)
NSLEEP: R8.2, R9.1, U3.1 (~SLEEP)
SENS_IRQ: J5.5, U1.29 (GPIO23)
SW_CT: C15.1, U4.3 (CT)
SW_NODE: L1.1, U2.7 (SW)
UART_RX: J6.3, U1.30 (U0RXD/GPIO17)
UART_TX: J6.2, U1.31 (U0TXD/GPIO16)
USB_DN: U1.17 (GPIO12/USB_D-), U6.6 (I/O1)
USB_DN_CONN: J1.A7 (D-), J1.B7 (D-), U6.1 (I/O1)
USB_DP: U1.18 (GPIO13/USB_D+), U6.4 (I/O2)
USB_DP_CONN: J1.A6 (D+), J1.B6 (D+), U6.3 (I/O2)
VBAT: C1.1, C2.1, Q1.2 (S), Q2.2 (S), R3.1, R4.1, U2.2 (VIN), U4.6 (VIN)
VBAT_DIV_TOP: Q2.3 (D), R1.1
VBAT_RAW: D1.1 (K), J2.1, Q1.3 (D)
VBAT_SENSE: C16.1, R1.2, R2.1, U1.12 (GPIO0)
VBAT_SENSE_EN: Q3.1 (G), U1.13 (GPIO1)
VBAT_SENSE_G: Q2.1 (G), Q3.3 (D), R3.2
VCP: C10.1, U3.11 (VCP)
VINT: C9.1, U3.14 (VINT)
VMOT: C4.1, C5.1, C8.1, C10.2, R8.1, U3.12 (VM), U4.1 (VOUT)
VUSB: C14.1, D1.2 (A), J1.A4 (VBUS), J1.A9 (VBUS), J1.B4 (VBUS), J1.B9 (VBUS), U6.5 (VBUS)

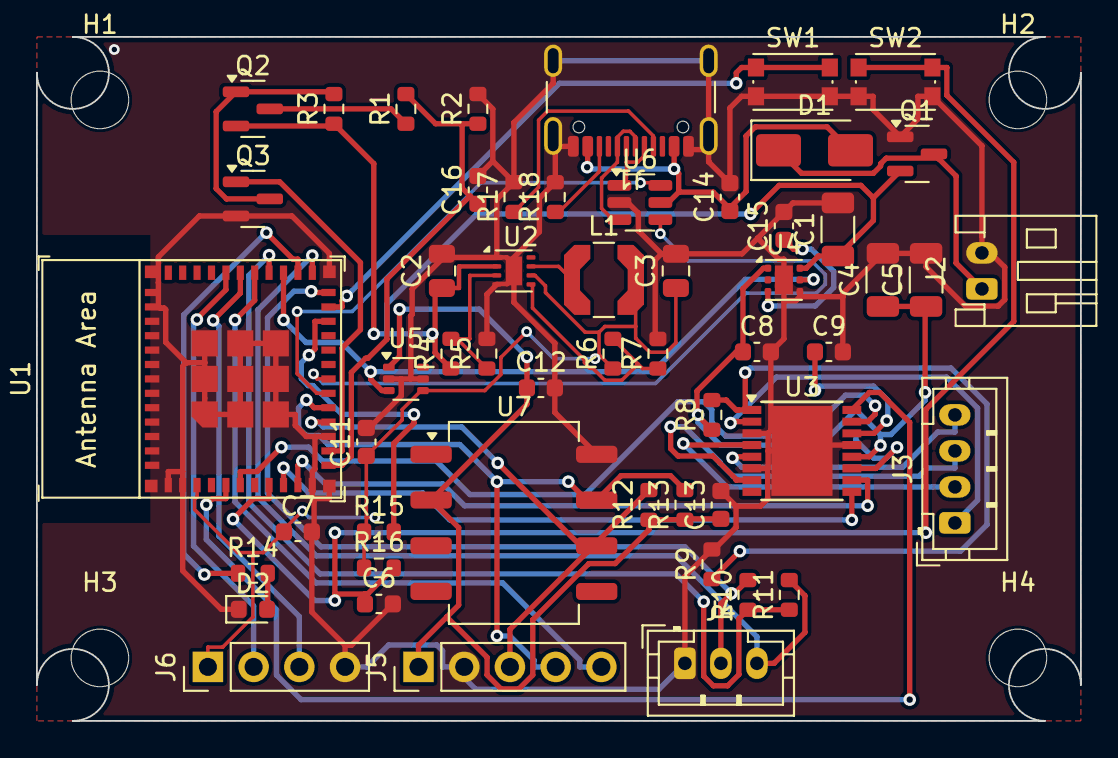
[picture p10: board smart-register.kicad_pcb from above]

Board: 2 copper layers, 58.0 x 38.0 mm, 59 parts (1 on the bottom side), 46 nets.

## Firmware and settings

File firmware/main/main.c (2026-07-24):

/*
 * main.c — smart register firmware entry point.
 *
 * Init order (docs/architecture.md): NVS -> board/stepper -> motion ->
 * pressure (bus only; sampling starts deferred once the Zigbee stack is up)
 * -> power management -> Zigbee task. Plus two local chores: the BOOT
 * button long-press (factory reset / re-pair) and the daily unloaded
 * battery housekeeping sample.
 */
#include <string.h>

#include "freertos/FreeRTOS.h"
#include "freertos/task.h"

#include "driver/gpio.h"
#include "esp_attr.h"
#include "esp_log.h"
#include "esp_timer.h"
#include "nvs_flash.h"
#include "sdkconfig.h"

#include "esp_zigbee_core.h"

#include "battery.h"
#include "board.h"
#include "nvs_state.h"
#include "pressure.h"
#include "stepper.h"
#include "zb_device.h"
#include "zb_sleep.h"

static const char *TAG = "main";

#define FACTORY_RESET_HOLD_MS  5000
#define BATTERY_PERIOD_MS      (24 * 60 * 60 * 1000) /* daily */
#define BATTERY_FIRST_DELAY_MS 30000

/* ---- BOOT button: long-press = factory reset / re-pair ------------------ */

static esp_timer_handle_t s_btn_timer;

static void btn_hold_check_cb(void *arg)
{
    (void)arg;
    if (gpio_get_level(PIN_BOOT_BTN) == 0) {
        ESP_LOGW(TAG, "BOOT held %d ms -> Zigbee factory reset",
                 FACTORY_RESET_HOLD_MS);
        /* Erases zb_storage and reboots into pairing (steering). */
        esp_zb_factory_reset();
    }
}

static void IRAM_ATTR btn_isr(void *arg)
{
    (void)arg;
    /* Falling edge: start (or restart) the hold timer from ISR. */
    esp_timer_stop(s_btn_timer);
    esp_timer_start_once(s_btn_timer, (uint64_t)FACTORY_RESET_HOLD_MS * 1000);
}

static void button_init(void)
{
    gpio_config_t btn = {
        .pin_bit_mask = 1ULL << PIN_BOOT_BTN,
        .mode = GPIO_MODE_INPUT,
        .pull_up_en = GPIO_PULLUP_ENABLE, /* strap pin, active low */
        .pull_down_en = GPIO_PULLDOWN_DISABLE,
        .intr_type = GPIO_INTR_NEGEDGE,
    };
    ESP_ERROR_CHECK(gpio_config(&btn));

    const esp_timer_create_args_t targs = {
        .callback = btn_hold_check_cb,
        .name = "btn_hold",
    };
    ESP_ERROR_CHECK(esp_timer_create(&targs, &s_btn_timer));

    ESP_ERROR_CHECK(gpio_install_isr_service(0));
    ESP_ERROR_CHECK(gpio_isr_handler_add(PIN_BOOT_BTN, btn_isr, NULL));
}

/* ---- Daily unloaded battery sample --------------------------------------
 * The honest state-of-charge number comes from the loaded sample taken
 * during moves (stepper.c -> on_battery_loaded); this daily unloaded
 * reading is a low-rate backstop for registers that rarely move. */
static void battery_task(void *arg)
{
    (void)arg;
    vTaskDelay(pdMS_TO_TICKS(BATTERY_FIRST_DELAY_MS));
    for (;;) {
        uint32_t mv = battery_hw_read_pack_mv();
        if (mv > 0) {
            uint8_t pct = battery_percent_from_unloaded_mv(mv);
            ESP_LOGI(TAG, "battery (unloaded): %lu mV ~ %u %%",
                     (unsigned long)mv, pct);
            zb_device_update_battery(mv, pct);
        }
        vTaskDelay(pdMS_TO_TICKS(BATTERY_PERIOD_MS));
    }
}

/* ---- Entry point --------------------------------------------------------- */

void app_main(void)
{
    ESP_LOGI(TAG, "smart register starting");

    /* 1. NVS first — everything below restores state from it. */
    ESP_ERROR_CHECK(nvs_state_init());

    /* 2. Board + stepper hardware (GPIO, GPTimer; rails stay off). */
    ESP_ERROR_CHECK(stepper_init());
    ESP_ERROR_CHECK(battery_hw_init() == 0 ? ESP_OK : ESP_FAIL);
    button_init();

    /* 3. Motion controller: restores position/range, forces a re-home if a
     *    move was interrupted (move_pending flag), wires reporting callbacks
     *    into zb_device. */
    ESP_ERROR_CHECK(motion_start(
        (const motion_callbacks_t *)zb_device_motion_callbacks()));

    /* 4. Pressure: fail-safe config from NVS + I2C bus. Sampling itself
     *    starts via the deferred driver init in zb_device.c once the stack
     *    is running. */
    ESP_ERROR_CHECK(pressure_init());

    /* 5. Zigbee platform + power management. zb_sleep_init() must precede
     *    esp_zb_init() (inside the zigbee task) — the stack latches the
     *    sleep-enable flag at init. */
    esp_zb_platform_config_t platform_cfg = {
        .radio_config = ESP_ZB_DEFAULT_RADIO_CONFIG(),
        .host_config = ESP_ZB_DEFAULT_HOST_CONFIG(),
    };
    ESP_ERROR_CHECK(esp_zb_platform_config(&platform_cfg));
    ESP_ERROR_CHECK(zb_sleep_init());

    /* 6. Zigbee device task (clusters, commissioning, main loop). */
    ESP_ERROR_CHECK(zb_device_start());

    /* 7. Housekeeping. */
    xTaskCreate(battery_task, "battery", 3072, NULL, 3, NULL);

    ESP_LOGI(TAG, "init complete (open=%u%%, fault=%u)",
             motion_current_open_pct(), motion_fault_code());
}

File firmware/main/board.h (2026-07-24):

/*
 * board.h — pin map for the smart register.
 *
 * SINGLE SOURCE OF TRUTH is the pin table in docs/architecture.md; this
 * header mirrors it exactly. The board variant is selected with
 * `idf.py menuconfig` -> "Smart Register Board" (Kconfig.projbuild):
 *   CONFIG_BOARD_DEVKITC1 — ESP32-C6-DevKitC-1 bring-up jig (default)
 *   CONFIG_BOARD_REVA     — Rev A register PCB
 *
 * The two variants differ only in the STATUS_LED pin (Rev A: GPIO20
 * discrete LED; DevKitC-1: GPIO8 onboard LED*).
 *
 * NOTE: GPIO10/11 are NOT bonded out on the ESP32-C6-MINI-1 module — never
 * assign them. Free spares: GPIO14, GPIO15.
 *
 * *The DevKitC-1 "LED" on GPIO8 is a WS2812 addressable part; driven as a
 * plain GPIO it will not light. Good enough for logic-analyzer bring-up;
 * attach a discrete LED to GPIO8 if a visible identify blink is needed.
 */
#ifndef SMART_REGISTER_BOARD_H
#define SMART_REGISTER_BOARD_H

/* --- Battery measurement ------------------------------------------------- */
#define PIN_VBAT_SENSE      0   /* ADC1_CH0, 1 M / 330 k divider */
#define PIN_VBAT_SENSE_EN   1   /* high = divider connected (NFET -> P-FET) */
#define VBAT_ADC_CHANNEL    0   /* ADC1 channel for GPIO0 on ESP32-C6 */

/* Divider ratio: Vpin = Vbat * 330k / (1M + 330k). */
#define VBAT_DIV_NUM        1330
#define VBAT_DIV_DEN        330

/* --- Stepper driver (DRV8833, 28BYJ-48 bipolar mod) ---------------------- */
#define PIN_MOTOR_AIN1      2
#define PIN_MOTOR_AIN2      3
#define PIN_MOTOR_BIN1      4
#define PIN_MOTOR_BIN2      5

/* --- Pressure sensor I2C (on switched 3V3_SENS rail) --------------------- */
#define PIN_I2C_SDA         6
#define PIN_I2C_SCL         7

/* --- Buttons ------------------------------------------------------------- */
#define PIN_BOOT_BTN        9   /* boot strap; long-press = factory reset / pair */

/* --- Debug UART header --------------------------------------------------- */
#define PIN_UART_TX         16
#define PIN_UART_RX         17

/* --- Limit switches (active low, only valid while LIMIT_SENSE_EN high) --- */
#define PIN_LIMIT_OPEN      18  /* closes to GND at full-open travel */
#define PIN_LIMIT_CLOSED    19  /* closes to GND at full-closed travel */

/* --- Power gating (docs/power-budget.md design rules) ---------------------
 * One GPIO gates BOTH switched rails: VMOT (TPS22810 from VBAT: DRV8833)
 * and 3V3_SENS (SiP32431 from 3.3 V: pressure sensor + I2C pull-ups). */
#define PIN_MOTOR_PWR_EN    21  /* high = motor + sensor rails powered */
#define PIN_LIMIT_SENSE_EN  22  /* sources limit-switch pull-ups during moves only */

/* --- Remote-sensor header spare ------------------------------------------ */
#define PIN_SENS_IRQ        23  /* reserved (input) */

/* --- Status LED ---------------------------------------------------------- */
#if defined(CONFIG_BOARD_REVA)
#define PIN_STATUS_LED      20
#elif defined(CONFIG_BOARD_DEVKITC1)
#define PIN_STATUS_LED      8   /* onboard (see note above) */
#else
/* Host builds never include this header; on target one board must be chosen. */
#define PIN_STATUS_LED      8
#endif

#endif /* SMART_REGISTER_BOARD_H */

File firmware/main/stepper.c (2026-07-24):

/*
 * stepper.c — DRV8833 half-step engine + motion controller (target-only).
 * See stepper.h. Spec: docs/architecture.md "Damper control".
 *
 * Move sequence (power-budget design rule): MOTOR_PWR_EN high -> 5 ms rail
 * settle -> LIMIT_SENSE_EN high -> step -> coils off -> both enables low.
 */
#include "stepper.h"

#include <string.h>

#include "freertos/FreeRTOS.h"
#include "freertos/task.h"
#include "freertos/queue.h"
#include "freertos/semphr.h"

#include "driver/gpio.h"
#include "driver/gptimer.h"
#include "esp_attr.h"
#include "esp_log.h"
#include "esp_rom_sys.h"

#include "board.h"
#include "battery.h"
#include "damper.h"
#include "failsafe.h" /* pure header — fault code values only */
#include "nvs_state.h"

static const char *TAG = "stepper";

/* ---- Mechanism constants ------------------------------------------------ */
/* 28BYJ-48: ~4096 half-steps/output-rev; ~3:1 pinion->sector; ~90 deg vane
 * travel => ~3072 half-steps closed->open. Used only as the pre-calibration
 * estimate; the real range comes from limit-switch calibration (NVS). */
#define DEFAULT_RANGE_STEPS   3072
#define MOVE_STEP_RATE_HZ     600  /* docs: 500-800 half-steps/s */
#define HOMING_STEP_RATE_HZ   300  /* homing at reduced rate */
#define HOMING_BACKOFF_STEPS  48   /* back off the switch after homing */
#define RAIL_SETTLE_MS        5
#define LIMIT_DEBOUNCE_READS  2    /* consecutive active reads */
#define BATTERY_SAMPLE_DELAY_MS 300 /* into the move, under full load */

/* Half-step drive table for a bipolar motor on DRV8833: one row per
 * half-step, columns AIN1, AIN2, BIN1, BIN2. Increasing index = toward
 * OPEN (swap here if the Rev A wiring turns out mirrored). */
static const uint8_t k_half_step[8][4] = {
    { 1, 0, 0, 0 }, /* A+       */
    { 1, 0, 1, 0 }, /* A+ B+    */
    { 0, 0, 1, 0 }, /*    B+    */
    { 0, 1, 1, 0 }, /* A- B+    */
    { 0, 1, 0, 0 }, /* A-       */
    { 0, 1, 0, 1 }, /* A- B-    */
    { 0, 0, 0, 1 }, /*    B-    */
    { 1, 0, 0, 1 }, /* A+ B-    */
};

/* ---- Step-engine (ISR) state ------------------------------------------- */

typedef enum {
    STEP_RES_DONE = 0,     /* target step count reached */
    STEP_RES_LIMIT_OPEN,   /* stopped on OPEN limit (debounced) */
    STEP_RES_LIMIT_CLOSED, /* stopped on CLOSED limit (debounced) */
    STEP_RES_WATCHDOG,     /* max_steps exceeded — stall/homing timeout */
    STEP_RES_STOPPED,      /* aborted by motion_request_stop() */
} step_result_t;

typedef struct {
    int8_t direction;          /* +1 toward open, -1 toward closed */
    int32_t target_steps;      /* stop after this many steps */
    int32_t max_steps;         /* hard watchdog (>= target_steps) */
    bool stop_on_open_limit;
    bool stop_on_closed_limit;
} step_run_cfg_t;

static struct {
    step_run_cfg_t cfg;
    volatile int32_t steps_taken;
    volatile step_result_t result;
    volatile bool active;
    uint8_t phase;             /* index into k_half_step */
    uint8_t open_hits;         /* debounce counters */
    uint8_t closed_hits;
} s_run;

static gptimer_handle_t s_timer;
static SemaphoreHandle_t s_run_done;
static volatile bool s_stop_req;

/* ---- Switched-rail refcount -------------------------------------------- */

static SemaphoreHandle_t s_rail_mutex;
static int s_rail_refs;

void motion_rail_acquire(void)
{
    xSemaphoreTake(s_rail_mutex, portMAX_DELAY);
    if (s_rail_refs++ == 0) {
        gpio_set_level(PIN_MOTOR_PWR_EN, 1);
        vTaskDelay(pdMS_TO_TICKS(RAIL_SETTLE_MS)); /* rail settle */
    }
    xSemaphoreGive(s_rail_mutex);
}

void motion_rail_release(void)
{
    xSemaphoreTake(s_rail_mutex, portMAX_DELAY);
    if (s_rail_refs > 0 && --s_rail_refs == 0) {
        gpio_set_level(PIN_MOTOR_PWR_EN, 0);
    }
    xSemaphoreGive(s_rail_mutex);
}

/* ---- Coil / limit helpers ---------------------------------------------- */

static void coils_write(const uint8_t row[4])
{
    gpio_set_level(PIN_MOTOR_AIN1, row[0]);
    gpio_set_level(PIN_MOTOR_AIN2, row[1]);
    gpio_set_level(PIN_MOTOR_BIN1, row[2]);
    gpio_set_level(PIN_MOTOR_BIN2, row[3]);
}

static void coils_off(void)
{
    static const uint8_t off[4] = { 0, 0, 0, 0 };
    coils_write(off);
}

/* ---- GPTimer ISR: one half-step per alarm ------------------------------ */

static bool IRAM_ATTR step_timer_cb(gptimer_handle_t timer,
                                    const gptimer_alarm_event_data_t *edata,
                                    void *user_ctx)
{
    (void)timer;
    (void)edata;
    (void)user_ctx;
    BaseType_t hp_woken = pdFALSE;

    if (!s_run.active) {
        return false;
    }

    step_result_t res = (step_result_t)-1;

    if (s_stop_req) {
        res = STEP_RES_STOPPED;
    } else {
        /* Limit switches: active low, valid only while LIMIT_SENSE_EN is
         * high (which it is for the whole run). Debounce = 2 consecutive
         * active reads (docs/architecture.md). */
        if (s_run.cfg.stop_on_open_limit) {
            s_run.open_hits = (gpio_get_level(PIN_LIMIT_OPEN) == 0)
                                  ? (uint8_t)(s_run.open_hits + 1) : 0;
            if (s_run.open_hits >= LIMIT_DEBOUNCE_READS) {
                res = STEP_RES_LIMIT_OPEN;
            }
        }
        if (res == (step_result_t)-1 && s_run.cfg.stop_on_closed_limit) {
            s_run.closed_hits = (gpio_get_level(PIN_LIMIT_CLOSED) == 0)
                                    ? (uint8_t)(s_run.closed_hits + 1) : 0;
            if (s_run.closed_hits >= LIMIT_DEBOUNCE_READS) {
                res = STEP_RES_LIMIT_CLOSED;
            }
        }
        if (res == (step_result_t)-1) {
            if (s_run.steps_taken >= s_run.cfg.target_steps) {
                res = STEP_RES_DONE;
            } else if (s_run.steps_taken >= s_run.cfg.max_steps) {
                res = STEP_RES_WATCHDOG;
            }
        }
    }

    if (res != (step_result_t)-1) {
        s_run.result = res;
        s_run.active = false;
        xSemaphoreGiveFromISR(s_run_done, &hp_woken);
        return hp_woken == pdTRUE;
    }

    /* Advance one half-step. */
    s_run.phase = (uint8_t)((s_run.phase + (s_run.cfg.direction > 0 ? 1 : 7)) & 7);
    coils_write(k_half_step[s_run.phase]);
    s_run.steps_taken++;
    return hp_woken == pdTRUE;
}
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

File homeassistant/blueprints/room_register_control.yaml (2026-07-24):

blueprint:
  name: "OpenRegister: room register control (proportional)"
  description: >-
    Proportional control of one OpenRegister SR-4x10 smart register from a room
    temperature sensor and a target temperature. Runs at a fixed interval,
    computes the temperature error, maps it across a proportional band to a
    damper position (100 = fully open = airflow), quantizes the result and
    only moves the register when the change is at least one quantization step
    — every skipped move is battery saved.

    Target temperature can come from a number/input_number helper, or — if a
    climate entity is provided — from that thermostat's setpoint (the climate
    entity takes precedence while it is available).

    Create one automation from this blueprint per room/register.
  domain: automation
  author: OpenRegister
  homeassistant:
    min_version: "2024.6.0"
  input:
    room_temp_sensor:
      name: Room temperature sensor
      description: Temperature sensor located in the room this register serves.
      selector:
        entity:
          domain: sensor
          device_class: temperature
    target_temperature:
      name: Target temperature entity
      description: >-
        Number or input_number helper holding the room setpoint (degC).
        Ignored while the optional climate entity below is set and available.
      selector:
        entity:
          domain:
            - input_number
            - number
    climate_entity:
      name: Climate entity (optional)
      description: >-
        Optional thermostat whose target temperature overrides the helper
        above. Leave empty to use the helper only.
      default: ""
      selector:
        entity:
          domain: climate
    register_cover:
      name: Register cover entity
      description: The SR-4x10 cover entity (position 100 = open = airflow).
      selector:
        entity:
          domain: cover
    hvac_mode:
      name: Heat/cool mode
      description: >-
        heat: open the register when the room is below target.
        cool: open the register when the room is above target.
      default: heat
      selector:
        select:
          options:
            - heat
            - cool
    minimum_position:
      name: Minimum position
      description: >-
        Never command the register below this position (%). Use a non-zero
        value to guarantee some airflow per room; whole-system protection is
        the job of the pressure floor guard blueprint.
      default: 0
      selector:
        number:
          min: 0
          max: 100
          step: 5
          unit_of_measurement: "%"
          mode: slider
    proportional_band:
      name: Proportional band
      description: >-
        Temperature error (degC) that maps to a fully open register. Example:
        with a 2.0 degC band, an error of 1.0 degC commands 50% open.
      default: 2.0
      selector:
        number:
          min: 0.5
          max: 10
          step: 0.1
          unit_of_measurement: "degC"
          mode: box
    deadband:
      name: Deadband
      description: >-
        Hold the current position while the absolute temperature error is
        below this (degC). Prevents hunting around the setpoint.
      default: 0.3
      selector:
        number:
          min: 0.0
          max: 2.0
          step: 0.05
          unit_of_measurement: "degC"
          mode: box
    update_interval:
      name: Update interval
      description: How often to re-evaluate the register position (minutes).
      default: 5
      selector:
        number:
          min: 1
          max: 60
          step: 1
          unit_of_measurement: min
          mode: box
    position_step:
      name: Position step quantization
      description: >-
        Positions are rounded to multiples of this step, and the register is
        only moved when the commanded change is at least one step. Larger
        steps = fewer motor moves = longer battery life.
      default: 10
      selector:
        number:
          min: 1
          max: 50
          step: 1
          unit_of_measurement: "%"
          mode: slider

mode: single
max_exceeded: silent

trigger:
  # Fires every minute; the first condition gates execution down to the
  # configured update interval (time_pattern cannot take a templated interval).
  - platform: time_pattern
    minutes: "/1"
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

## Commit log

2026-07-24 M0: repo scaffold, architecture + power-budget docs, CI workflows
    - docs/architecture.md: block diagram, pin map, Zigbee device model
    (Window Covering + Pressure Measurement + mfr-specific 0xFC00 fail-safe
    cluster), sleep/polling strategy, damper control and fail-safe design
    - docs/power-budget.md: ~150 uA average -> ~2.4 yr on 4x AA LiFeS2
    - CI: firmware (host tests + ESP-IDF build), cad (pytest + STL/STEP
    artifacts), pcb (KiCad ERC/DRC + gerbers)
    - README: project overview and layout
    Claude-Session: https://claude.ai/code/session_01FGLsJEuzYz8WLhA21PPbYv
2026-07-24 Add comprehensive purchasable BOM
    Per-register electronics (SDP810 and XGZP6897D cost-down variants),
    passives, electromechanical parts, PCB fab, dev-bench bring-up kit,
    totals and substitution notes.
    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
2026-07-24 M2: ESP-IDF Zigbee firmware with host-tested control logic
    ESP32-C6 sleepy end device (esp-zigbee-sdk): Window Covering cover with
    lift/open inversion isolated in damper.c, Pressure Measurement with Pa-scale
    ScaledValue, Power Config battery reporting, Poll Control, and mfr-specific
    0xFC00 fail-safe cluster (code 0x131B). Stepper module with half-step drive,
    limit-switch homing, NVS move_pending protocol and stall lockout; SDP810
    driver with adaptive sampling and XGZP auto-zero hook; autonomous fail-open
    state machine with zero ESP-IDF includes.
    Host tests (vendored Unity): 46 tests green across damper/failsafe/battery.
    Docs updated: pin map corrected (GPIO10/11 not bonded on the MINI-1 mod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
    [partitions.csv]
2026-07-24 M1: parametric build123d CAD for the 4x10 drop-in register
    Single RegisterParams dataclass drives all geometry (REGISTER_4X10 +
    REGISTER_4X12 presets): faceplate with grille and battery door, 4 linked
    shingling vanes with tie-bar crank linkage, 12t pinion -> 135-degree sector
    (3:1) drivetrain with cam-actuated D2F limit switches, sealed e-bay with
    vertical PCB mount (ESP32 antenna above the boot line), pressure snorkel
    with room-reference vent, battery tray + door. export.py writes STL/STEP
    for all 11 parts plus assembly.step.
    25 pytest checks: solids, pairwise interference at closed pose, mechanism
    sweep at 45/90 degrees, gear mesh + exact center distance, fit chains,
    PCB standoff contract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
    [drivetrain.py]
2026-07-24 M3: KiCad rev A board, code-generated, DRC-clean, orderable
    58x38 mm 2-layer board generated end-to-end from tools/design.py: schematic
    (embedded v7 symbols, netlist verified against the canonical design via
    kicad-cli), placed board with antenna keep-out, Freerouting session, GND
    pours with per-island stitching vias, and deterministic hand-repairs for
    the two fine-pitch corridors the autorouter cannot finish. Net classes:
    Default 0.3/0.2, fine-pitch USB+buck 0.2/0.13 (in .kicad_pro for CI DRC).
    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
    [bom.csv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]
2026-07-24 M4: Home Assistant layer - Z2M converter, ZHA quirk, blueprints
    Zigbee2MQTT external converter (modernExtend): cover with position, battery,
    Pa-resolution pressure from ScaledValue, 0xFC00 fail-safe exposures
    (tripped, writable threshold/hysteresis, auto-clear, fault enum) and sleepy-
    safe reporting config. ZHA quirks-v2 equivalent verified against zigpy 1.6 +
    zha-quirks registry. Blueprints: per-room P-control with deadband, 10% step
    quantization and 5-min rate limit to protect battery; pressure-floor guard
    that sums open percentages (unavailable = closed), force-opens to cover the
    deficit and notifies on fail-safe trips.
    Claude-Sessio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
    [room_register_control.yaml]
2026-07-24 Add PNG renders: CAD assembly/parts, PCB layers, schematic
    cad/render.py tessellates each part and the positioned assembly with
    build123d and renders shaded PNGs via matplotlib (no GPU needed); PCB and
    schematic images come from kicad-cli SVG export + rsvg. Key renders
    committed to docs/img and linked from the README.
    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
